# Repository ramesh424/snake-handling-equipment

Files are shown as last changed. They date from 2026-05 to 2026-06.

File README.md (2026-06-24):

# Open-Source Cable-Actuated Snake Rescue Tool with Rotation-Assisted Body Winding for Controlled Head Restraint

This repository contains the open-source hardware design files, documentation, bill of materials, assembly instructions, operation protocol, validation data, and demonstration media for a low-cost cable-actuated snake rescue tool.

The tool is designed for long-reach snake handling and prototype-stage evaluation using a flexible dummy snake or rubber tube. The mechanism combines cable-actuated body gripping, spring-assisted jaw reopening, compliant soft-grip jaw pads, and manually controlled working-end rotation. After initial body engagement, the working-end assembly is rotated manually so that the snake body winds around the gripper/shaft region, reducing uncontrolled movement and supporting controlled head-restraint positioning.

> **Important safety note:** This prototype has been validated only using a dummy snake/rubber tube. It is not a field-certified live-snake rescue device. Live-animal use should only be performed by trained snake rescuers or authorized wildlife personnel under applicable ethical approval, local wildlife regulations, and expert supervision.

---

## Repository overview

This project supports open-source replication and further development of a cable-actuated snake rescue tool for trained wildlife rescue and educational demonstration contexts.

The repository includes:

* Editable CAD files
* Printable STL/3MF files
* Bill of materials
* Assembly instructions
* Operation protocol
* Validation dataset
* Rendered figures
* Demonstration media
* License files

---

## Hardware summary

| Field | Description |
| --- | --- |
| Hardware name | Open-source cable-actuated snake rescue tool with rotation-assisted body-winding restraint mechanism and compliant soft-grip jaw interface |
| Subject area | Wildlife rescue engineering; field safety equipment; humane animal handling; open-source mechanical hardware |
| Hardware type | Long-reach mechanical rescue tool; cable-actuated gripping mechanism; manually rotatable body-winding restraint hardware |
| Closest commercial analog | Conventional snake tongs and animal handling poles used for wildlife rescue and reptile handling operations |
| Estimated cost | Approximately INR 2296 per unit, excluding manufacturing scale-up, transportation, and supplier-dependent cost variation |
| Hardware license | CERN Open Hardware Licence Version 2 – Weakly Reciprocal |
| Documentation license | Creative Commons Attribution 4.0 International |

---

## Key features

* Long-reach aluminium shaft for maintaining operator distance
* Bicycle-style brake lever for simple cable actuation
* Steel cable transmission system
* Spring-return jaw linkage for automatic reopening
* Compliant soft-grip jaw pads for improved contact distribution
* Manually rotatable working-end assembly
* Rotation-assisted body-winding mechanism
* Modular 3D-printed support components
* Low-cost and locally repairable construction
* Open-source design files for replication and modification

---

## Operating principle

The intended functional sequence is:

1. **Approach**
   The operator approaches the snake from a safe distance using the long aluminium shaft.

2. **Initial body grip**
   The working-end jaw is positioned around a suitable body region, and the brake-style trigger is actuated.

3. **Secure body capture**
   The cable-actuated jaw closes using compliant soft-grip pads to hold the dummy snake body.

4. **Working-end rotation**
   The operator manually rotates the working-end assembly about the shaft axis.

5. **Body winding around gripper/shaft region**
   The captured body rotates and winds around the gripper/shaft region.

6. **Controlled head-restraint positioning**
   As body winding progresses, the head is brought into a controlled restrained position during dummy-snake testing.

7. **Spring-assisted release**
   Releasing the trigger allows the spring-return jaw to reopen for controlled release or transfer.

---

## Repository structure

snake-handling-equipment/
├── README.md
├── LICENSE
├── LICENSE-DOCUMENTATION
├── CAD/
│   ├── STEP/
│   ├── STL/
│   ├── 3MF/
│   └── Source_CAD/
├── 3D_Printing_Files/
├── Bill_of_Materials/
│   ├── BOM_snake_rescue_tool.csv
│   └── BOM_snake_rescue_tool.xlsx
├── Assembly_Instructions/
│   └── assembly_manual.pdf
├── Operation_Protocol/
│   └── operation_protocol.pdf
├── Validation_Data/
│   ├── validation_dataset.csv
│   └── validation_dataset.xlsx
├── Figures/
│   ├── exploded_component_layout.png
│   ├── annotated_full_assembly.png
│   ├── multi_view_cad.png
│   ├── initial_body_engagement.png
│   ├── soft_grip_jaw_closeup.png
│   └── working_end_rotation_test.png
└── Demonstration_Media/
    └── operation_sequence_video.mp4
```

---

## Design files

The design package includes editable and printable files required to reproduce the tool.

| Design file category               | File types              | Description                                 |
| ---------------------------------- | ----------------------- | ------------------------------------------- |
| Main assembly                      | `.step`, `.stl`, `.3mf` | Complete assembled tool model               |
| Movable jaw/grip component         | `.step`, `.stl`, `.3mf` | Movable gripping component                  |
| Grip back support                  | `.step`, `.stl`         | Rear jaw/grip support part                  |
| Hex back support for grip assembly | `.step`, `.stl`         | Support component for jaw assembly          |
| Insert rod component               | `.step`, `.stl`, `.3mf` | Rod insertion support                       |
| Side-base support                  | `.step`, `.stl`, `.3mf` | Main side-base support                      |
| Side-base angle rod insert         | `.step`, `.stl`         | Angled rod insert support                   |
| Cable-passing support              | `.step`, `.stl`         | Cable guide/support component               |
| Rear cable-passing support         | `.step`, `.stl`         | Rear cable guide component                  |
| Side bolt base                     | `.step`, `.stl`, `.3mf` | Bolt support component                      |
| Support wedge                      | `.step`, `.stl`         | Wedge support part                          |
| Support wedge revision 1           | `.step`, `.stl`         | Revised wedge support part                  |
| Rendered figures                   | `.png`, `.jpg`          | Assembly, operation, and validation figures |
| Demonstration video                | `.mp4`                  | Functional operation demonstration          |

---

## Bill of materials

The estimated fabrication cost is approximately **INR 2296 per unit**.

| Component                               | Quantity | Estimated cost |
| --------------------------------------- | -------: | -------------: |
| Aluminium hollow shaft/tube             |        1 |        INR 350 |
| Angled aluminium handle tube            |        1 |        INR 180 |
| Bicycle brake lever/trigger             |        1 |        INR 250 |
| Steel brake cable                       |        1 |         INR 80 |
| Cable outer housing/Bowden sleeve       |        1 |        INR 100 |
| 3D-printed cable guide/support parts    |        4 |        INR 240 |
| 3D-printed side-base/support parts      |        4 |        INR 280 |
| 3D-printed jaw/grip support parts       |        3 |        INR 195 |
| Stainless steel linkage strips          |        2 |        INR 180 |
| Extension spring for jaw return         |        1 |         INR 45 |
| Soft rubber/TPU gripping pads           |        2 |         INR 80 |
| Pivot bolts, nuts, washers, and spacers |    1 set |        INR 140 |
| Cable stopper/clamp and adjuster        |    1 set |         INR 75 |
| Rear grip/end cap                       |        1 |         INR 70 |
| Adhesive/finishing consumables          |    1 set |         INR 31 |
| **Total**                               |          |   **INR 2296** |

Costs may vary depending on supplier, material grade, 3D-printing method, and local availability.

---

## Assembly overview

The tool is assembled in seven stages:

1. Preparation of fabricated and printed parts
2. Main shaft assembly
3. Operator handle and trigger assembly
4. Cable-routing assembly
5. Working-end jaw and rotating mechanism assembly
6. Final cable tensioning and alignment
7. Functional checking before validation

Detailed build instructions are provided in the `Assembly_Instructions/` folder.

---

## Validation summary

Prototype-stage mechanical validation was performed using a flexible dummy snake/rubber tube. No live snakes were used during the reported validation.

| Validation parameter                      | Result     |
| ----------------------------------------- | ---------- |
| Maximum jaw opening                       | 72 mm      |
| Minimum jaw gap after trigger pull        | 8 mm       |
| Soft pad contact width                    | 18 mm      |
| Average grip force                        | 7.06 N     |
| Trigger travel                            | 36 mm      |
| Cable displacement at working end         | 24 mm      |
| Trigger force required for jaw closure    | 12 N       |
| Maximum working-end rotation angle        | 360°       |
| Practical rotation range for body winding | 180°–270°  |
| Average release time                      | 0.80 s     |
| Trigger open-close cycles completed       | 100 cycles |
| Working-end rotation cycles completed     | 50 cycles  |

The validation confirmed the intended prototype operation sequence: cable-actuated initial body grip, secure body capture, spring-assisted jaw reopening, working-end rotation, body winding around the gripper/shaft region, controlled head-restraint positioning, and controlled release.

The results should be interpreted as prototype-stage mechanical characterization, not live-animal field performance validation.

---

## Safety and ethics

No live snakes were used during the prototype-stage validation reported for this project. All functional tests were performed using a flexible dummy snake/rubber tube to avoid animal stress, injury risk, and unnecessary live-animal handling during early-stage hardware development.

This tool is intended only for:

* trained snake rescuers,
* authorized wildlife personnel,
* supervised research demonstrations,
* educational prototype testing.

This tool should not be used by untrained individuals for live-snake handling. Any future live-snake evaluation should be conducted only under applicable institutional ethical approval, local wildlife regulations, and supervision by trained snake-handling experts.

---

## Limitations

The current prototype is an early-stage open-source hardware platform and should not be interpreted as a field-certified live-snake rescue device.

Key limitations include:

* Validation was performed using a dummy snake/rubber tube, not live snakes.
* Live-snake muscular resistance, defensive movement, surface friction, and strike behavior were not evaluated.
* Grip force depends on trigger input, cable tension, jaw geometry, and pad compliance.
* A calibrated mechanical force-limiting mechanism has not yet been integrated.
* The body-winding behavior may vary with snake size, body diameter, flexibility, surface texture, and environmental conditions.
* 3D-printed components require further durability testing.
* Cable wear, cable stretch, and tension loss require long-term evaluation.

Future work should include calibrated force limitation, improved working-end rotation locking, stronger cable-routing protection, expanded durability testing, ergonomic assessment, cleaning/disinfection evaluation, and controlled testing by trained handlers.

---

## Recommended citation

If you use or adapt this hardware design, please cite the related manuscript and Zenodo archive.

```text
Reddy, R. Open-Source Cable-Actuated Snake Rescue Tool with Rotation-Assisted Body Winding for Controlled Head Restraint. HardwareX manuscript under preparation.
```

After Zenodo upload, replace the above with:

```text
Reddy, R. Open-Source Cable-Actuated Snake Rescue Tool with Rotation-Assisted Body Winding for Controlled Head Restraint. Zenodo. DOI: [insert DOI]
```

---

## Licenses

Hardware design files are released under:

**CERN Open Hardware Licence Version 2 – Weakly Reciprocal (CERN-OHL-W v2)**

Documentation, figures, bill of materials, validation data, and demonstration media are released under:

**Creative Commons Attribution 4.0 International (CC BY 4.0)**

See the `LICENSE` and `LICENSE-DOCUMENTATION` files for details.

---

## Contact

For questions, feedback, or collaboration, please contact:

**Author:** [insert author name]
**Email:** [insert email address]
**Repository:** [insert GitHub repository URL]
**Zenodo DOI:** [insert Zenodo DOI]

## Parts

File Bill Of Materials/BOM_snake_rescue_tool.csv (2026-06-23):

Bill of Materials – Snake Rescue/Handling Tool
Component | Number | Cost per Unit (INR) | Total Cost (INR) | Source of Materials
Aluminium hollow shaft/tube | 1 | 350 | 350 | Local hardware/metal supplier
Angled aluminium handle tube | 1 | 180 | 180 | Local hardware/metal supplier
Bicycle brake lever/trigger | 1 | 250 | 250 | Bicycle spare-parts supplier
Steel brake cable | 1 | 80 | 80 | Bicycle spare-parts supplier
Cable outer housing/Bowden sleeve | 1 | 100 | 100 | Bicycle spare-parts supplier
3D-printed cable guide/support parts | 4 | 60 | 240 | FDM 3D printing
3D-printed side-base/support parts | 4 | 70 | 280 | FDM 3D printing
3D-printed jaw/grip support parts | 3 | 65 | 195 | FDM 3D printing
Stainless steel linkage strips | 2 | 90 | 180 | Local hardware supplier
Extension spring for jaw return | 1 | 45 | 45 | Local hardware supplier
Soft rubber/TPU gripping pads | 2 | 40 | 80 | Rubber sheet or TPU 3D printing
Pivot bolts, nuts, washers, and spacers | 1 set | 140 | 140 | Local hardware supplier
Cable stopper/clamp and adjuster | 1 set | 75 | 75 | Bicycle/hardware supplier
Rear grip/end cap | 1 | 70 | 70 | Local hardware supplier
Adhesive/finishing consumables | 1 set | 31 | 31 | Local hardware supplier
TOTAL |  |  | 2296

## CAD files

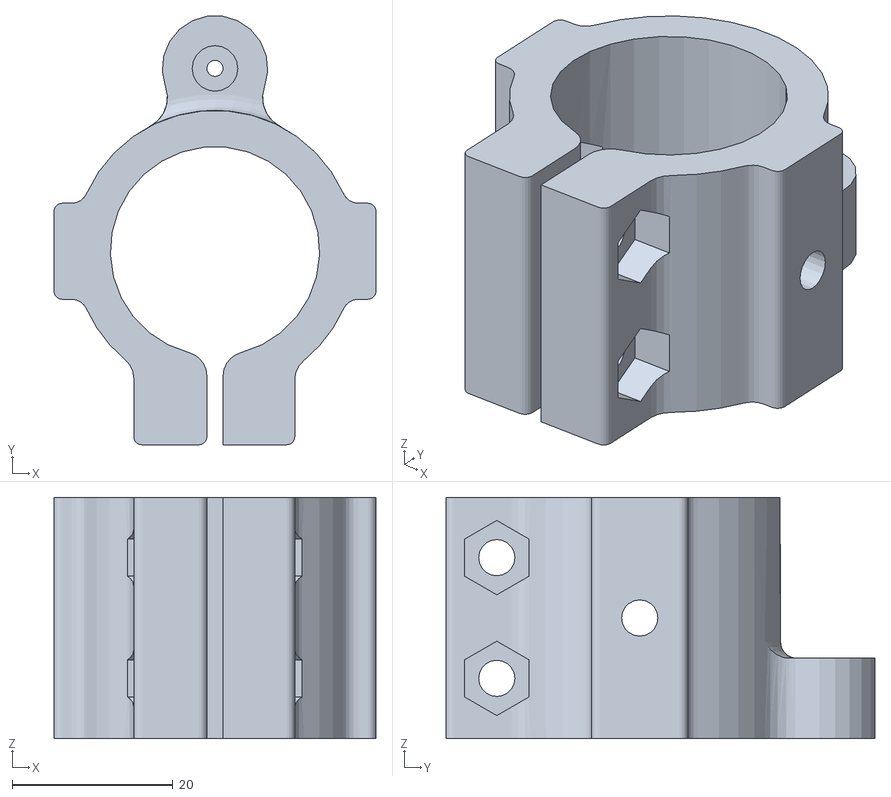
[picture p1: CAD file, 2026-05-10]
3d printing files/side base cable passing_bk.stl
40.0 x 53.2 x 30.0

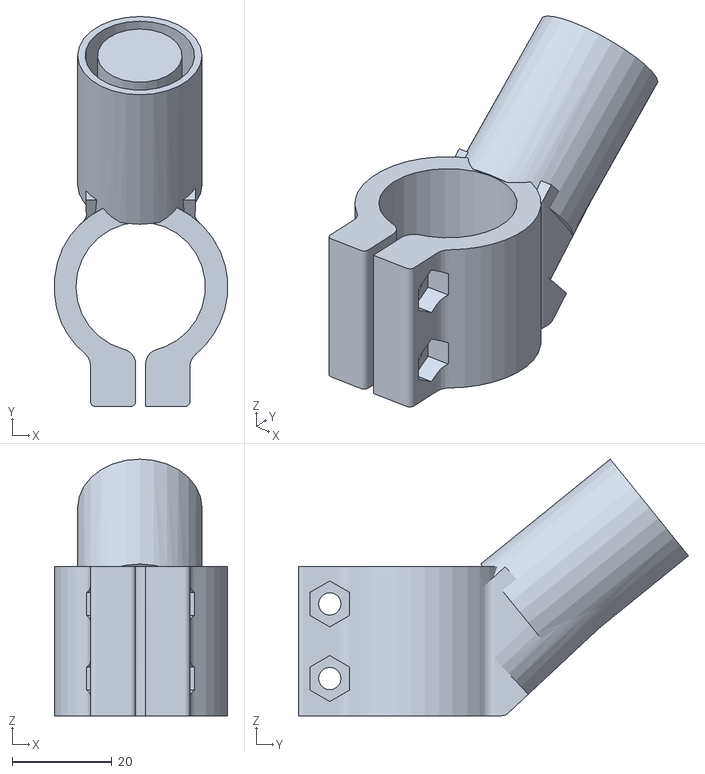
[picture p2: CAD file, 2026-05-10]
3d printing files/side base angle rod insert.stl
34.8 x 78.4 x 51.6

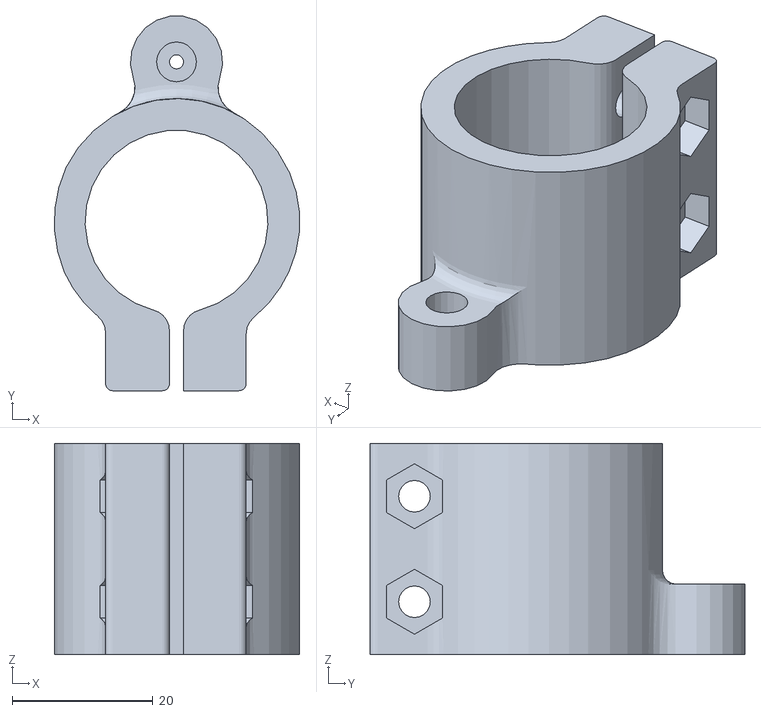
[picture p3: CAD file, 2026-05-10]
3d printing files/side base cable passing.stl
34.8 x 53.2 x 30.0

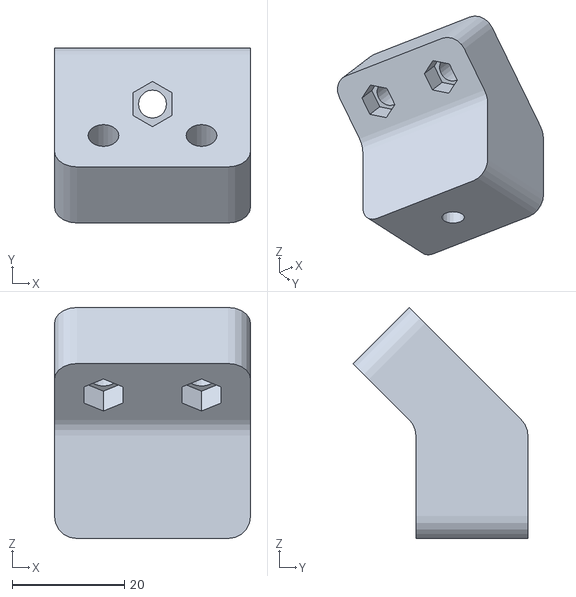
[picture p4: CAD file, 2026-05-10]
3d printing files/support wedge revission 1.stl
35.0 x 31.2 x 41.2

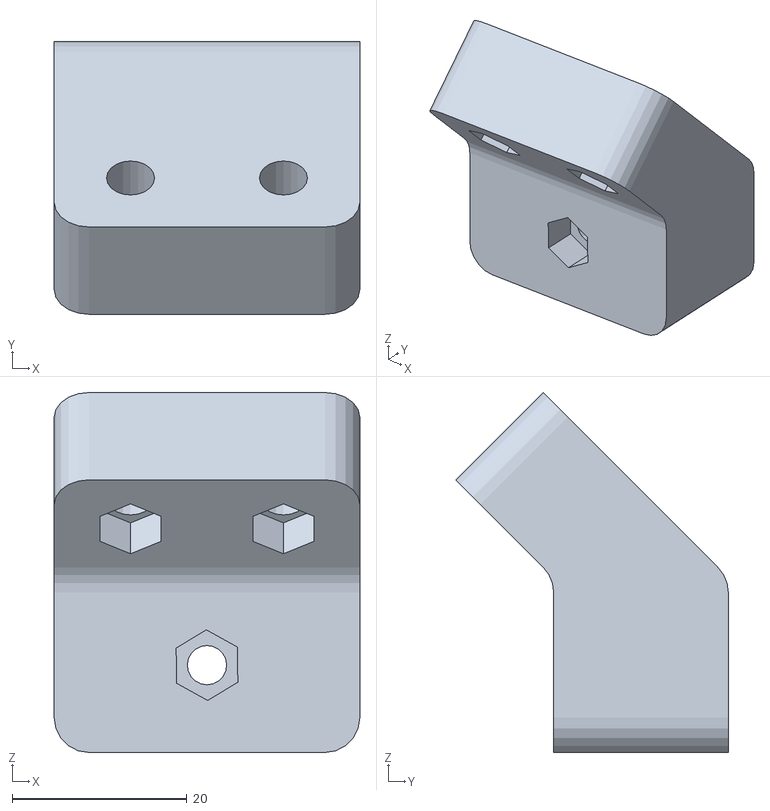
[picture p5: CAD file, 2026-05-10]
3d printing files/support wedge.stl
35.0 x 31.2 x 41.2

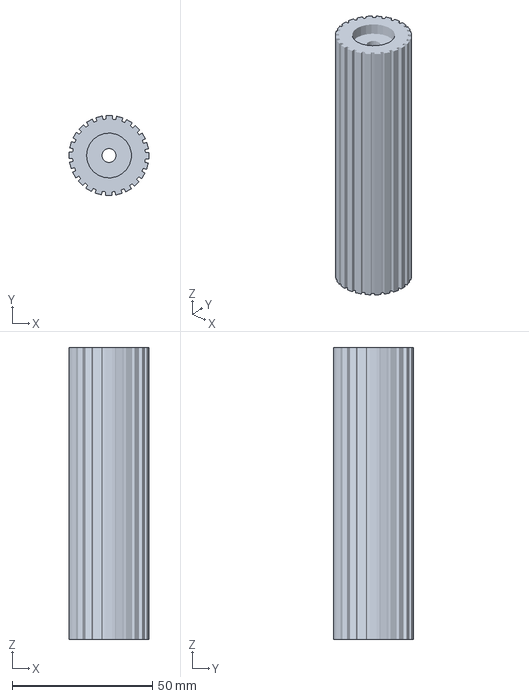
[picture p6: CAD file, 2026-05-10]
3d printing files/grip 2 movable.3mf
28.5 x 28.5 x 104.0 mm

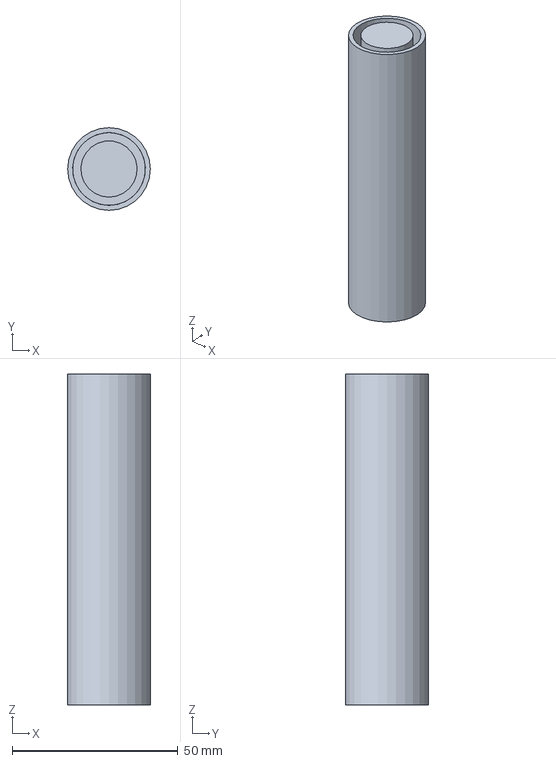
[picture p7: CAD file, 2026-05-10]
3d printing files/Insert rod.3mf
25.0 x 25.0 x 100.0 mm

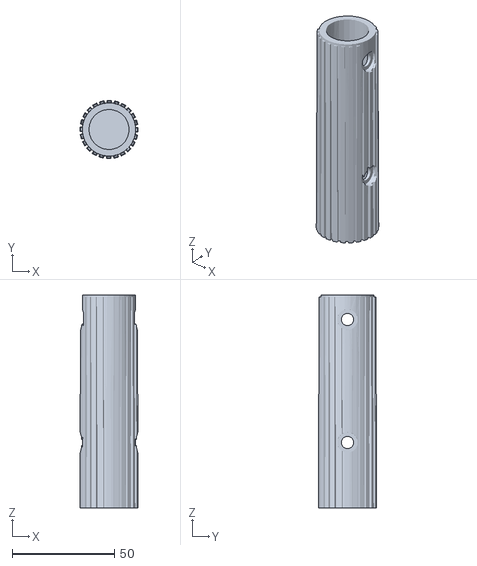
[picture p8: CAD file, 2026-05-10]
3d printing files/grip_bk.stl
28.5 x 28.5 x 104.0

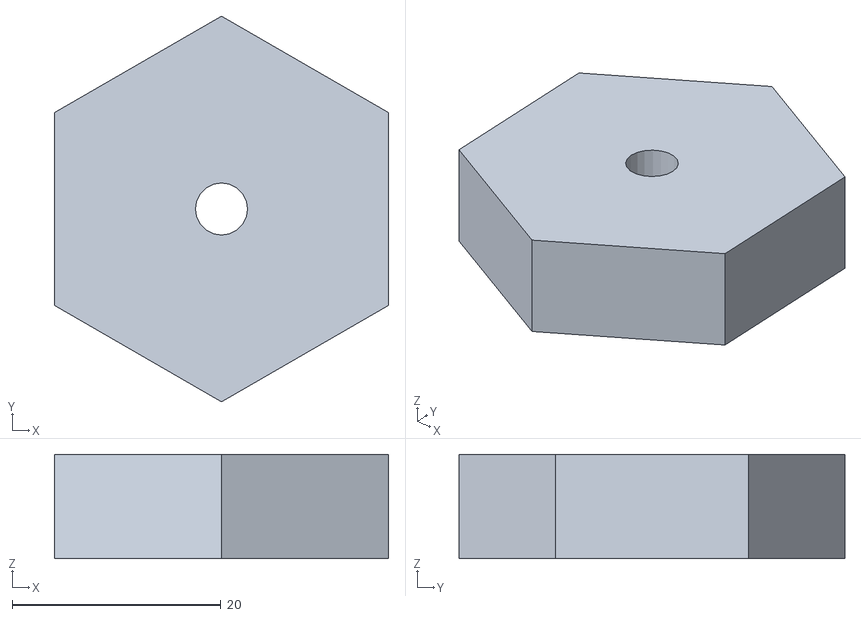
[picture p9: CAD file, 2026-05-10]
3d printing files/grip2 hex_bk.stl
32.0 x 37.0 x 10.0

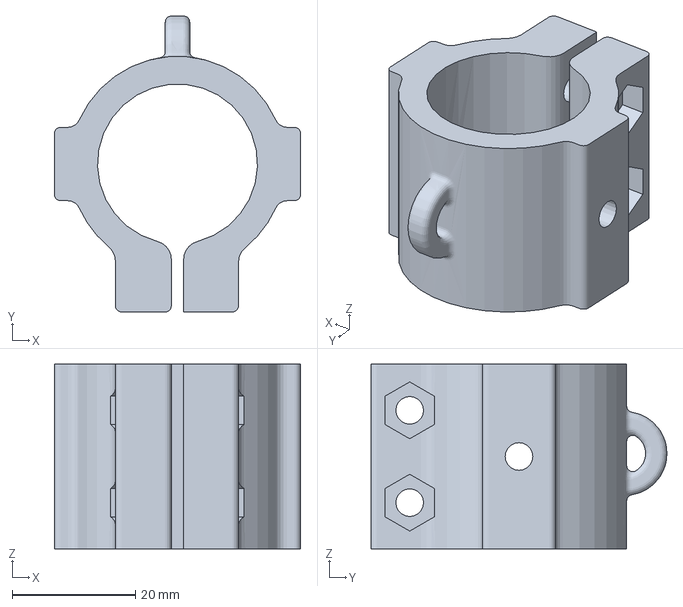
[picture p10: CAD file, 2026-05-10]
3d printing files/side base.3mf
40.0 x 48.1 x 30.0 mm

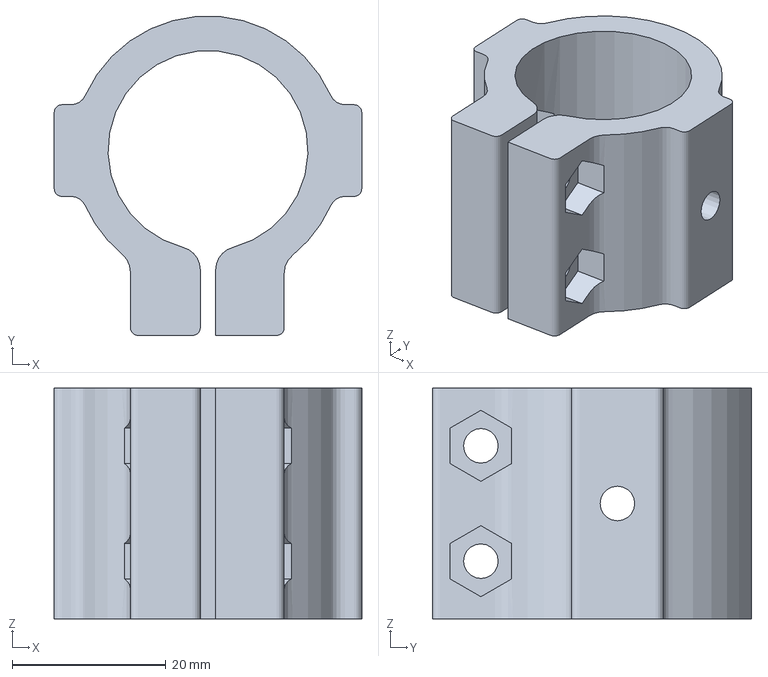
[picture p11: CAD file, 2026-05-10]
3d printing files/side bolt base.3mf
40.0 x 41.5 x 30.0 mm

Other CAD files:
3d printing files/Insert rod.stl
3d printing files/grip 2 movable.stl
3d printing files/side base.stl

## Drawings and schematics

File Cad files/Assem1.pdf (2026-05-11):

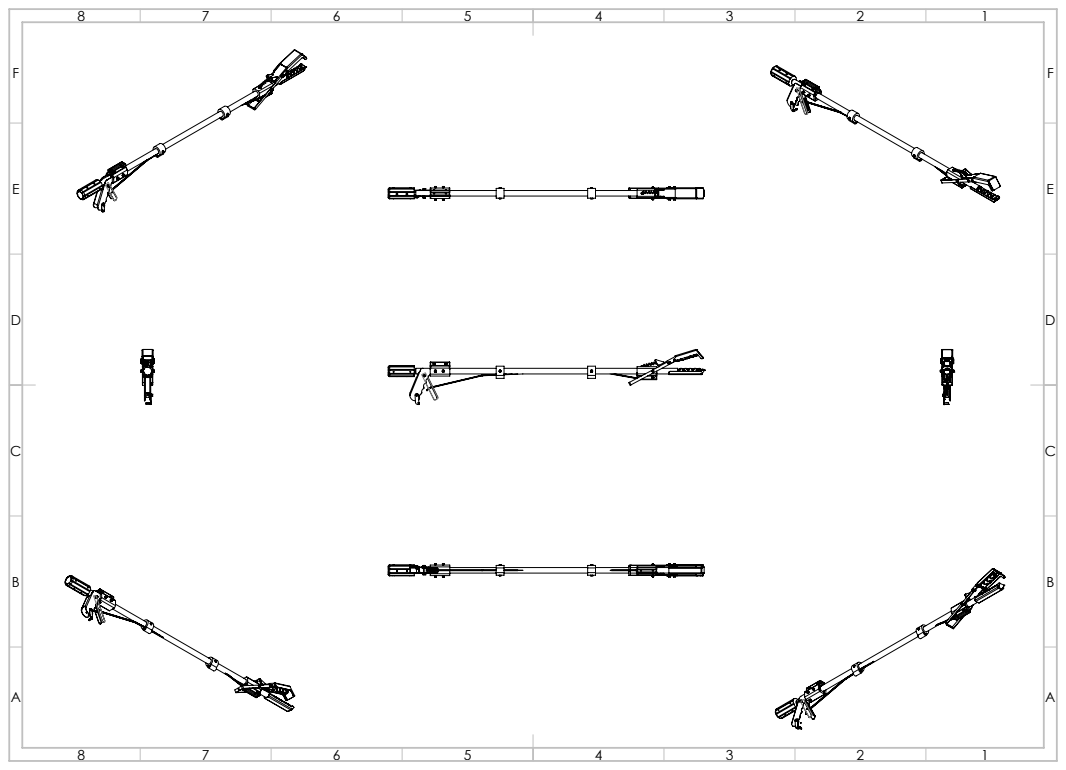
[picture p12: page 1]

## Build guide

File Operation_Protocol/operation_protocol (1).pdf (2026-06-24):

# Operation Protocol

### Open-Source Cable-Actuated Snake Rescue Tool with Rotation-Assisted Body Winding

For dummy-snake/rubber-tube prototype testing and trained-handler evaluation

Hardware name | Open-source cable-actuated snake rescue tool with rotation-assisted body-winding restraint mechanism and compliant soft-grip jaw interface
Document type | Operation protocol
Intended use | Prototype operation, dummy-snake testing, training demonstration, and controlled evaluation by trained personnel
Validation condition | Dummy snake / flexible rubber tube only
Live-animal use | Restricted to trained snake rescuers or authorized wildlife personnel under applicable ethical approval and local wildlife regulations

Safety notice: This tool is an early-stage open-source hardware prototype. The protocol below is intended for dummy-snake/rubber-tube functional testing and controlled demonstration. It is not a field-certified live-snake rescue procedure. Live-snake operation should only be performed by trained and authorized personnel with appropriate safety controls, local permissions, and ethical approval.

## 1. Purpose

This operation protocol describes the recommended functional sequence for using the cable-actuated snake rescue tool during prototype testing. The protocol explains initial body engagement, secure body capture, manual working-end rotation, body winding around the gripper/shaft region, controlled head-restraint positioning, and spring-assisted release.

## 2. Required equipment

- Assembled snake rescue tool with cable-actuated jaw, spring-return linkage, soft-grip jaw pads, and manually rotatable working-end assembly.
- Flexible dummy snake or rubber tube for prototype validation.
- Secure transport container or bucket for release/transfer demonstration.
- Personal protective equipment for trained evaluators, if required by the testing environment.
- Basic inspection tools, such as vernier caliper, spring scale/digital force gauge, and stopwatch, if measurements are being recorded.

## 3. Pre-operation inspection

- Confirm that all fasteners, collars, brackets, jaw pivots, linkage arms, and cable guides are tightened and aligned.
- Check that the brake-style trigger moves smoothly and returns to its original position after release.
- Check that the cable is correctly routed through the guide supports without sharp bends, fraying, slack loops, or rubbing.
- Confirm that the spring-return jaw opens automatically when the trigger is released.
- Inspect the soft-grip jaw pads for secure attachment, wear, cracks, or detachment.
- Manually rotate the working-end assembly through the expected rotation range and confirm that the cable, spring, linkage arms, and jaw pads do not twist, lock, or interfere.

- Use only a dummy snake or flexible rubber tube during prototype-stage testing unless live-animal testing has been approved and is conducted by trained personnel.

## 4. Functional operation sequence

The intended operation sequence is summarized in Table 1. The same sequence should be used during dummy-snake functional testing and demonstration.

Stage | Procedure
Stage 1 - Approach | Hold the tool by the operator handle and approach the dummy snake from a safe distance. Position the working-end jaw assembly near a suitable body region rather than directly targeting the head.
Stage 2 - Initial body grip | Pull the brake-style trigger to tension the steel cable and close the soft-grip jaw pads around the dummy snake body.
Stage 3 - Secure body capture | Maintain trigger input until the dummy snake body is held between the compliant jaw pads. Confirm that the body is engaged without visible slipping or jaw-pad detachment.
Stage 4 - Working-end rotation | After the body is captured, manually rotate the working-end assembly about the shaft axis using the secondary rotating control/working-end structure.
Stage 5 - Body winding | Continue controlled rotation so that the captured dummy snake body rotates and winds around the gripper/shaft region. Observe whether winding occurs without cable, spring, or linkage interference.
Stage 6 - Controlled head-restraint positioning | As body winding progresses, the dummy snake head is brought into a controlled restrained position near the working-end structure. This is demonstrated only under dummy-snake testing conditions.
Stage 7 - Spring-assisted release | Position the tool over a secure container or release area. Release the brake-style trigger and confirm that the spring-return jaw opens and the dummy snake can be removed or deposited without sticking.

## 5. Detailed procedure

## 5.1 Approach and positioning

Place the dummy snake on a clear test surface. Hold the tool using the operator handle and align the working-end jaw assembly with a suitable body region. Avoid placing the jaw directly on the head during the initial approach.

## 5.2 Trigger actuation

Pull the brake-style trigger gradually. The cable should transmit the input to the front linkage and close the jaw. The soft-grip jaw pads should contact the body surface and hold it without rigid metal contact.

## 5.3 Body-capture confirmation

Verify that the dummy snake body is held between the jaw pads. The jaw should remain aligned, and the cable should not slip from the guide supports. If the dummy snake slips immediately, adjust cable tension or jaw-pad contact before repeating the test.

## 5.4 Working-end rotation

Rotate the working-end assembly manually through the intended range. During rotation, observe the cable, spring, linkage arms, and jaw pads. Stop the test if binding, cable twisting, linkage locking, or pad detachment occurs.

## 5.5 Body winding around the gripper/shaft region

Continue rotation until the dummy snake body winds around the gripper/shaft region. This stage demonstrates the main rotation-assisted body-winding function of the prototype.

## 5.6 Controlled head-restraint positioning

Observe whether body winding reduces uncontrolled movement and brings the dummy snake head into a controlled restrained position near the working-end structure. This result should be reported as dummy-snake prototype behavior, not live-snake performance.

## 5.7 Release and reset

Move the tool over a secure release area or container. Release the trigger and confirm that the spring-return mechanism opens the jaw. Remove or deposit the dummy snake and reset the tool for the next test cycle.

## 6. Optional measurement protocol

The following measurements may be recorded during prototype validation:

- Maximum jaw opening and minimum jaw gap after trigger pull.
- Soft pad contact width.
- Grip force using a spring scale or digital force gauge.
- Trigger travel and cable displacement at the working end.
- Maximum working-end rotation angle and practical body-winding range.
- Slip distance before and after 90°, 180°, and 270° working-end rotation.
- Release time after trigger release.
- Number of repeated trigger open-close cycles and working-end rotation cycles.

## 7. Functional acceptance criteria

Stage | Procedure
Jaw actuation | Jaw closes when trigger is pulled and reopens when trigger is released.
Cable routing | Cable remains aligned in the guide supports without slipping or excessive rubbing.
Spring return | Spring returns the movable jaw to the open position after trigger release.
Soft-grip contact | Jaw pads remain attached and contact the dummy snake body without rigid metal-to-body contact.
Working-end rotation | Working end rotates through the intended range without cable, spring, or linkage interference.
Body winding | Dummy snake body rotates and winds around the gripper/shaft region during working-end rotation.
Release | Dummy snake can be released without sticking, jaw locking, or pad detachment.

## 8. Safety limitations and warnings

- This protocol does not certify the tool for live venomous snake handling.
- The tool should not be used by untrained individuals for live-snake rescue.
- Validation with a dummy snake does not reproduce live-snake muscular resistance, defensive movement, surface friction, body stiffness, or strike behavior.
- Grip force depends on trigger input, cable tension, jaw geometry, and pad compliance; a calibrated forcelimiting mechanism has not yet been integrated.

- Any future live-snake use must follow institutional ethics approval, local wildlife regulations, and supervision by trained snake-handling experts.

## 9. Post-operation inspection and maintenance

- Inspect the jaw pads for wear, detachment, or damage.
- Check the cable for fraying, loosening, or stretch.
- Inspect the spring, pivots, bolts, and linkage arms for deformation or loosening.
- Clean and disinfect contact surfaces if the tool is used in biological or field environments.
- Retighten fasteners and adjust cable tension before the next operation if looseness is observed.
- Record any failure, interference, or abnormal behavior in the validation log.

## 10. Version information

Protocol version | 1.0
Associated manuscript | Open-Source Cable-Actuated Snake Rescue Tool with Rotation-Assisted Body Winding for Controlled Head Restraint
Repository | [Insert GitHub repository URL]
Zenodo DOI | [Insert Zenodo DOI after archive release]
End of operation protocol

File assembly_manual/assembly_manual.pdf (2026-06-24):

Assembly Manual - Cable-Actuated Snake Rescue Tool | Prototype-stage documentation

# Assembly Manual

Open-Source Cable-Actuated Snake Rescue Tool with Rotation-Assisted Body Winding

Version 1.0 | Prototype-stage hardware documentation | Dummy-snake validation only

Safety notice: This hardware is an early-stage prototype. Assemble and test the tool only with a dummy snake or flexible rubber tube during prototype validation. Live-animal use must be restricted to trained snake rescuers or authorized wildlife personnel under applicable ethical approval, local wildlife regulations, and expert supervision.

## 1. Purpose and scope

This manual describes the assembly procedure for a low-cost cable-actuated snake rescue tool. The tool uses a long aluminium shaft, bicycle-style brake lever, steel actuation cable, spring-return jaw linkage, compliant soft-grip jaw pads, and a manually rotatable working-end assembly. The intended prototype operation sequence is initial body grip, secure body capture, working-end rotation, body winding around the gripper/shaft region, controlled head-restraint positioning, and spring-assisted release.

## 2. Main components

Component group | Examples
Structural parts | Aluminium main shaft, angled aluminium handle tube, rear grip/end cap
Actuation parts | Bicycle brake lever/trigger, steel brake cable, Bowden sleeve, cable stopper/clamp, adjuster
Jaw and linkage | Movable jaw/grip component, fixed jaw support, stainless steel linkage strips, pivot bolts, washers, spacers
Return mechanism | Extension spring for jaw reopening
Contact interface | Soft rubber or TPU gripping pads
3D-printed parts | Cable guides, side-base supports, insert components, wedge supports, working-end supports
Fasteners and consumables | Bolts, nuts, washers, lock nuts, adhesive, finishing consumables

## 3. Tools required

- Drill and suitable drill bits for clearing holes
- Allen keys/spanners for bolts and lock nuts
- Cable cutter or pliers
- Screwdriver
- Vernier caliper for dimensional checks
- Sandpaper or file for deburring
- Adhesive suitable for fixing soft jaw pads
- Personal protective equipment during fabrication and testing

## 4. Assembly instructions

The snake rescue tool is assembled in seven stages: preparation of fabricated and printed parts, main shaft assembly, operator handle and trigger assembly, cable-routing assembly, working-end jaw and rotating mechanism assembly, final cable tensioning and alignment, and functional checking before validation.

### 4.1 Preparation of fabricated and printed parts

Inspect all 3D-printed parts for dimensional accuracy, layer defects, blocked holes, rough surfaces, and warping. Compare the printed jaw components, side-base supports, cable-passing supports, insert-rod parts, wedge supports, shaft collars, and rotating working-end supports with the corresponding CAD files.

Clear bolt holes, cable-passing holes, and rod-insertion holes using a suitable drill bit where required. Lightly sand contact surfaces to remove printing burrs and to ensure smooth fitting with the aluminium shaft, rods, fasteners, and cable guides.

Check the soft gripping pads for correct size, thickness, seating, and adhesion before fixing them to the jaw contact surfaces.

Cut the aluminium tube used as the main shaft to the required length according to the CAD model. Deburr both ends of the tube to prevent cable damage and operator injury.

Check linkage rods and metallic strips for straightness and correct hole alignment. Arrange all bolts, nuts, washers, spacers, springs, cable clamps, and brake-cable components according to the bill of materials before final assembly.

### 4.2 Main shaft assembly

Position the printed insert-rod and side-base components on the main aluminium shaft according to the assembly layout.

Align the supports along the shaft axis to avoid twisting of the cable path and to maintain correct alignment during jaw actuation and working-end rotation.

Insert bolts and washers through the printed supports and tighten gradually. Do not over-tighten, because excessive force can deform or crack printed polymer components.

Mount the cable-guide supports along the shaft at regular intervals. These guides keep the actuation cable close to the shaft and reduce lateral movement during trigger operation.

After tightening the cable guides, visually check the cable path from the handle end to the working end to confirm that the route is straight and free from sharp bends.

### 4.3 Operator handle and trigger assembly

Fix the angled handle support near the operator end of the shaft using the printed side-base and rod-insert components.

Select the handle angle so that the user can operate the tool with one hand while keeping the wrist in a natural position.

Mount the bicycle-style brake lever on the handle and secure it firmly using the clamp screw. Position the lever so that the operator can pull the trigger without changing hand position.

Insert the brake cable through the trigger lever and seat the cable end properly inside the lever slot to prevent slipping during repeated actuation.

Before connecting the cable to the working-end jaw mechanism, pull the lever several times to confirm smooth movement and complete return to its original position.

### 4.4 Cable-routing assembly

Route the steel actuation cable from the brake lever along the shaft through the printed cable-guide supports.

Use a Bowden sleeve or cable-passing support wherever the cable passes through curved or contact-prone regions to prevent rubbing against the shaft or printed parts.

Keep the cable slightly tensioned during routing to avoid slack loops.

At the working end, pass the cable through the jaw-side cable guide and connect it to the movable jaw linkage using a cable stopper or clamp.

Do not fully tighten the cable at this stage. Leave a small amount of adjustment for final tensioning after the jaw linkage and spring-return mechanism are installed.

### 4.5 Working-end jaw and rotating mechanism assembly

Attach the fixed jaw support to the front printed base. Connect the movable jaw component using pivot bolts, washers, and lock nuts.

Tighten the pivot bolts only enough to remove lateral play while still allowing free jaw movement. Avoid excessive tightening because it increases friction and reduces jaw response.

Connect the linkage arms between the cable attachment point and the movable jaw. Use washers or spacers at linkage joints to maintain clearance between moving parts.

After linkage installation, manually open and close the jaw several times to confirm smooth motion and to check that no printed part interferes with the linkage path.

Attach the extension spring between the jaw linkage and the fixed support point. Orient the spring so that it automatically reopens the jaw when the trigger is released.

Check the spring through the full jaw movement range to ensure that it does not collide with linkage arms, cable, or printed supports.

Fix the soft gripping pads to the inner jaw contact surfaces. These pads provide a compliant contact interface and increase friction during dummy-snake gripping tests.

Mount the manually rotatable working-end assembly coaxially with the shaft. Check that the jaw assembly can rotate about the shaft axis while maintaining jaw alignment and grip contact.

Rotate the working-end assembly manually through the expected working range. During rotation, inspect the cable, spring, linkage arms, and jaw pads to ensure that no twisting, locking, rubbing, or cable interference occurs. This check is essential because working-end rotation produces the body-winding action around the gripper/shaft region.

### 4.6 Final cable tensioning and alignment

After the shaft, handle, cable, jaw, spring, and rotating working-end assemblies are installed, tension the actuation cable at the jaw-side cable stopper.

Pull the trigger slowly while observing jaw closure. Adjust cable tension until the jaw closes fully under trigger operation and reopens automatically when the trigger is released.

Do not over-tighten the cable. Excessive preload can keep the jaw partially closed and reduce spring-return performance.

Check jaw opening, jaw closure, trigger return, spring return, and working-end rotation repeatedly.

Tighten all fasteners using hand tools. Use lock nuts at moving joints where possible to reduce loosening during repeated actuation.

Inspect the final assembly for sharp edges, exposed cable ends, loose fasteners, cable rubbing, excessive joint play, jaw pad detachment, and working-end rotation interference. Trim and cap exposed cable ends to prevent injury.

### 4.7 Functional check before validation

Operate the tool without load for repeated open-close cycles. Observe the trigger, cable, linkage, spring return, jaw pads, and manually rotatable working-end assembly during each cycle.

Test the jaw using a flexible rubber tube or dummy snake. Engage the dummy snake at a body region using the soft-grip jaw pads and actuate the brake-style trigger to achieve initial body grip and secure body capture.

After the dummy snake body is held, rotate the working-end assembly manually. This rotation should cause the captured dummy snake body to rotate and wind around the gripper/shaft region.

After rotation, release the trigger to confirm that the spring-return jaw opens and that the dummy snake can be removed without sticking.

The tool is ready for characterization only after the jaw opens and closes smoothly, the spring returns the jaw reliably, the cable remains aligned during actuation, the rotating working-end assembly moves without interference, the soft jaw pads remain fixed, and no structural looseness is observed during dummy-snake handling.

## 5. Pre-validation checklist

- All sharp edges removed and exposed cable ends capped
- Jaw opens and closes smoothly without binding
- Spring returns jaw reliably after trigger release
- Cable route is aligned and free from sharp bends
- Working-end assembly rotates without cable, spring, or linkage interference
- Soft jaw pads remain fixed during dummy-snake gripping
- Fasteners are tight and lock nuts are used at moving joints where possible
- Dummy snake can be gripped, rotated, body-wound, and released without sticking

## 6. Safety and limitation statement

This manual supports prototype assembly and dummy-snake functional checking only. The controlled head-restraint positioning and body-winding behavior described in this project have been demonstrated only using a flexible dummy snake/rubber tube. They should not be interpreted as validated live-snake restraint performance. Live-animal testing or deployment should only be performed by trained and authorized personnel under appropriate ethical approval, local wildlife regulations, and expert supervision.

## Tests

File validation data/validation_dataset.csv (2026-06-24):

Section | Test | Parameter | Trial | Value | Unit | Result/Status | Notes
Jaw opening and closing performance | Jaw opening | Maximum jaw opening |  | 72 | mm |  | Measured using vernier caliper
Jaw opening and closing performance | Jaw closing | Minimum jaw gap after trigger pull |  | 8 | mm |  | Measured after full trigger actuation
Jaw opening and closing performance | Jaw pad | Soft pad contact width |  | 18 | mm |  | Compliant soft-grip contact surface
Jaw opening and closing performance | Spring return | Jaw reopening after trigger release |  |  | Successful | Spring-assisted reopening observed
Jaw opening and closing performance | Repeated open-close cycles | Number of repeated open-close trials |  | 100 | cycles | Completed | No manual jaw resetting required
Grip-force characterization | Grip force | Grip force | Trial 1 | 6.8 | N |  | Measured using spring scale/digital force gauge
Grip-force characterization | Grip force | Grip force | Trial 2 | 7.2 | N |  | Measured using spring scale/digital force gauge
Grip-force characterization | Grip force | Grip force | Trial 3 | 7.0 | N |  | Measured using spring scale/digital force gauge
Grip-force characterization | Grip force | Grip force | Trial 4 | 7.4 | N |  | Measured using spring scale/digital force gauge
Grip-force characterization | Grip force | Grip force | Trial 5 | 6.9 | N |  | Measured using spring scale/digital force gauge
Grip-force characterization | Grip force | Average grip force |  | 7.06 | N |  | Average of five grip-force trials
Trigger response and cable actuation | Trigger response | Trigger travel |  | 36 | mm |  | Brake-style trigger travel
Trigger response and cable actuation | Cable actuation | Cable displacement at working end |  | 24 | mm |  | Observed at working-end linkage
Trigger response and cable actuation | Trigger force | Trigger force required for jaw closure |  | 12 | N |  | Required for full jaw closure
Trigger response and cable actuation | Cable reliability | Cable slippage observed |  |  | No | No slippage during test
Trigger response and cable actuation | Cable routing | Cable-guide interference observed |  |  | No | No guide interference during actuation
Working-end rotation and body-winding test | Working-end rotation | Maximum working-end rotation angle |  | 360 | degrees |  | Manual rotation range
Working-end rotation and body-winding test | Working-end rotation | Practical rotation range for body winding |  | 180-270 | degrees |  | Practical working range observed
Working-end rotation and body-winding test | Working-end rotation | Rotation tested per trial |  | 180 | degrees |  | Rotation used in test trials
Working-end rotation and body-winding test | Cable reliability | Cable interference during rotation |  |  | No | No cable interference during working-end rotation
Working-end rotation and body-winding test | Spring/linkage reliability | Spring/linkage interference during rotation |  |  | No | No spring/linkage interference observed
Working-end rotation and body-winding test | Body winding | Dummy-snake body winding observed |  |  | Yes | Body wound around gripper/shaft region
Slip-resistance test | Slip resistance | Slip distance without working-end rotation |  | 42 | mm |  | Measured under gentle axial pull
Slip-resistance test | Slip resistance | Slip distance after 90-degree rotation |  | 26 | mm |  | Measured under gentle axial pull
Slip-resistance test | Slip resistance | Slip distance after 180-degree rotation |  | 14 | mm |  | Measured under gentle axial pull
Slip-resistance test | Slip resistance | Slip distance after 270-degree rotation |  | 10 | mm |  | Measured under gentle axial pull
Release-time test | Release response | Release time | Trial 1 | 0.82 | s |  | Trigger released after body-wound position
Release-time test | Release response | Release time | Trial 2 | 0.76 | s |  | Trigger released after body-wound position
Release-time test | Release response | Release time | Trial 3 | 0.79 | s |  | Trigger released after body-wound position
Release-time test | Release response | Release time | Trial 4 | 0.84 | s |  | Trigger released after body-wound position
Release-time test | Release response | Release time | Trial 5 | 0.78 | s |  | Trigger released after body-wound position
Release-time test | Release response | Average release time |  | 0.80 | s |  | Average of five release-time trials
Tool weight and handling length | Physical measurement | Overall tool length |  | 910 | mm |  | Prototype measurement
Tool weight and handling length | Physical measurement | Main shaft length |  | 760 | mm |  | Prototype measurement
Tool weight and handling length | Physical measurement | Total tool weight |  | 0.95 | kg |  | Prototype measurement
Tool weight and handling length | Physical measurement | Working-end jaw assembly length |  | 145 | mm |  | Prototype measurement
Tool weight and handling length | Physical measurement | Operator handle length |  | 130 | mm |  | Prototype measurement
Durability and repeated-cycle test | Durability | Trigger open-close cycles completed |  | 100 | cycles | Completed | Short-term repeated actuation test
Durability and repeated-cycle test | Durability | Working-end rotation cycles completed |  | 50 | cycles | Completed | Short-term repeated rotation test
Durability and repeated-cycle test | Durability | Cable loosening observed |  |  | Minor / adjustable | Did not prevent operation
Durability and repeated-cycle test | Durability | Spring deformation observed |  |  | No | No permanent spring deformation observed
Durability and repeated-cycle test | Durability | Printed part cracking observed |  |  | No | No cracking observed
Durability and repeated-cycle test | Durability | Fastener loosening observed |  |  | Minor at one joint | Adjustable during maintenance
Durability and repeated-cycle test | Durability | Jaw pad detachment observed |  |  | No | Jaw pads remained fixed
Validation summary | Summary | Intended operation sequence verified |  |  | Yes | Prototype-stage mechanical characterization with dummy snake/rubber tube

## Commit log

2026-05-10 Rename Insert rod.3mf to 3d printing files/Insert rod.3mf
    [Insert rod.3mf]
2026-05-10 Rename Insert rod.stl to 3d printing files/Insert rod.stl
    [Insert rod.stl]
2026-05-11 Rename Assem1.pdf to Cad files/Assem1.pdf
2026-05-11 Rename BOM_snake_rescue_tool.xlsx to Bill Of Materials/BOM_snake_rescue_tool.xlsx
    [BOM_snake_rescue_tool.xlsx]
2026-06-23 Rename BOM_snake_rescue_tool.csv to Bill Of MAterials/BOM_snake_rescue_tool.csv
    [BOM_snake_rescue_tool.csv]
2026-06-24 Rename Screenshot 2026-06-24 080139.png to Figures/Annotated full assembly
2026-06-24 Rename Screenshot 2026-06-24 080252.png to Figures/cad view
2026-06-24 Rename validation_dataset.csv to validation data/validation_dataset.csv
    [validation_dataset.csv]
